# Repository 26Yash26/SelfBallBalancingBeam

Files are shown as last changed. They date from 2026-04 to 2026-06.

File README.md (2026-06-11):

# 🏓 Ping Pong Ball Balancer

> A PID-controlled system that autonomously balances a ping pong ball at the centre of a 420 mm bar using an ESP32-S3, dual VL53L0X time-of-flight sensors, and an MG995 servo motor.

```
[LEFT TOF]  <── dL ──── ● ──── dR ──>  [RIGHT TOF]
                    ball position = L − dR  (primary)

Servo tilts bar ──> ball rolls toward centre (210 mm)
```

---

## Table of Contents

1. [Project Overview](#1-project-overview)
2. [Hardware](#2-hardware)
3. [Hardware Pivot: Stepper → Servo](#3-hardware-pivot-stepper--servo)
4. [Wiring](#4-wiring)
5. [Mechanical Design (CAD)](#5-mechanical-design-cad)
6. [Sensor Reliability & Fusion](#6-sensor-reliability--fusion)
7. [PID Controller](#7-pid-controller)
8. [Hyperparameters](#8-hyperparameters)
9. [PID Tuning Procedure](#9-pid-tuning-procedure)
10. [Arduino IDE Setup](#10-arduino-ide-setup)
11. [Serial Monitor Output](#11-serial-monitor-output)
12. [Troubleshooting](#12-troubleshooting)

---

## 1. Project Overview

This project implements a closed-loop PID control system that balances a ping pong ball at the midpoint of a 420 mm aluminium bar. Two VL53L0X time-of-flight sensors measure the ball's position from each end; an ESP32-S3 microcontroller runs the control loop at 30 ms intervals; and an MG995 metal-gear servo physically tilts the bar to drive the ball back to the 210 mm setpoint.

The design went through one major hardware pivot — an initial attempt using a stepper motor was abandoned in favour of the MG995 servo. That journey is documented in [Section 3](#3-hardware-pivot-stepper--servo).

---

## 2. Hardware

| Component | Model / Spec | Notes |
|---|---|---|
| Microcontroller | ESP32-S3 N8R8 | Dual-core, 8 MB flash, 8 MB PSRAM |
| ToF Sensors ×2 | Adafruit VL53L0X | I2C, up to 2 m range; default addr `0x29` |
| Servo Motor | MG995 (metal gear) | 4.8–7.2 V, stall torque 13 kg·cm |
| Bar | 420 mm aluminium channel | Sensing distance between sensors |
| Power Supply | 5 V / 3 A dedicated | For servo only — never use ESP32 rail |

---

## 3. Hardware Pivot: Stepper → Servo

### 3.1 Initial Design — Stepper Motor Approach

The first iteration used a stepper motor for bar actuation, on the premise that steppers offer precise, repeatable positioning without a motor-side feedback sensor. Components used:

| Part | Model |
|---|---|
| Motor | NEMA 17 bipolar stepper — 17HS4401, 1.7 A/phase, 1.8°/step |
| Driver | A4988 stepper driver module (Pololu-style pinout) |
| Encoder | 600 PPR incremental rotary encoder (A/B quadrature) mounted on bar pivot shaft |

The encoder was added to provide absolute angle feedback, since the stepper could lose steps under rapid reversals.

### 3.2 Why It Didn't Work

Several fundamental problems emerged during testing:

- **Resonance and mid-speed torque drop** — The NEMA 17 exhibits a well-known torque null around 200–400 steps/sec, which coincided exactly with the bar oscillation frequency the PID loop was trying to command. The motor would stall or miss steps mid-correction.

- **Latency** — Step-pulse generation within a tight 30 ms PID loop created timing jitter. Achieving smooth motion required interrupt-driven step/dir code that conflicted with the I2C polling of both VL53L0X sensors.

- **Holding current noise** — At standstill, the stepper's holding current injected electrical noise into the 3.3 V rail, causing intermittent I2C bus errors on both sensors.

- **Encoder complexity** — Adding a quadrature encoder for actual angle tracking introduced interrupt-driven counter code and debouncing without resolving the core torque and latency problems.

- **Physical bulk** — The NEMA 17 + A4988 + encoder assembly was mechanically oversized for a lightweight ping pong bar, introducing unwanted rotational inertia at the pivot.

### 3.3 The Pivot — MG995 RC Servo

The system was redesigned around an MG995 metal-gear RC servo, which solved every listed problem:

- **Direct angle command** — A PWM pulse (500–2400 µs) maps directly to a shaft angle. No step counting, no lost-step risk, no encoder required.
- **Software speed limiting** — The `SERVO_SPEED` hyperparameter (max degrees per loop cycle) replaces mechanical damping with smooth, controllable motion.
- **Electrical isolation** — The servo runs from a dedicated 5 V/3 A rail; its signal line on GPIO 3 keeps the I2C bus clean.
- **Compact and lightweight** — At 55 g, the MG995 mounts directly under the bar pivot with a standard servo horn.

> **Trade-off:** The MG995 has a rated positioning accuracy of ~±1° and a dead-band of ~5 µs, which sets a practical lower bound on `DEADBAND_MM` (~25 mm). This is acceptable for the project goals.

---

## 4. Wiring

### 4.1 ToF Sensors — Dual I2C Buses

Both VL53L0X sensors share the default I2C address `0x29` and cannot share a bus without address remapping. Instead, two hardware I2C peripherals on the ESP32-S3 are used — one per sensor — eliminating any need to toggle XSHUT lines. **Leave XSHUT unconnected on both sensors.**

| ESP32-S3 Pin | Left VL53L0X | Right VL53L0X |
|---|---|---|
| GPIO 8 (SDA0) | SDA | — |
| GPIO 9 (SCL0) | SCL | — |
| GPIO 6 (SDA1) | — | SDA |
| GPIO 7 (SCL1) | — | SCL |
| 3.3V | VIN | VIN |
| GND | GND | GND |

### 4.2 MG995 Servo

| ESP32-S3 Pin | MG995 Wire | Notes |
|---|---|---|
| GPIO 3 | Signal (orange/yellow) | PWM via ESP32Servo library |
| GND (shared) | GND (black) | Must share with ESP32 GND |
| External 5V / 3A | VCC (red) | **Never** use ESP32 3.3V rail |

> ⚠️ **Warning:** The MG995 draws up to 2.5 A under stall load. Powering it from the ESP32's 3.3 V rail will brown-out the board. Always use a dedicated 5 V/3 A supply with its GND tied to the ESP32 GND.

---

## 5. Mechanical Design (CAD)

The bar pivots at its midpoint on a 3D-printed mount. The MG995 servo horn connects to a linkage arm that converts rotational motion into bar tilt. VL53L0X sensor brackets at each end hold the modules pointing inward along the bar axis.

<!-- CAD IMAGE 1: Replace the path below with your actual image -->
**Figure 1 — Isometric View **
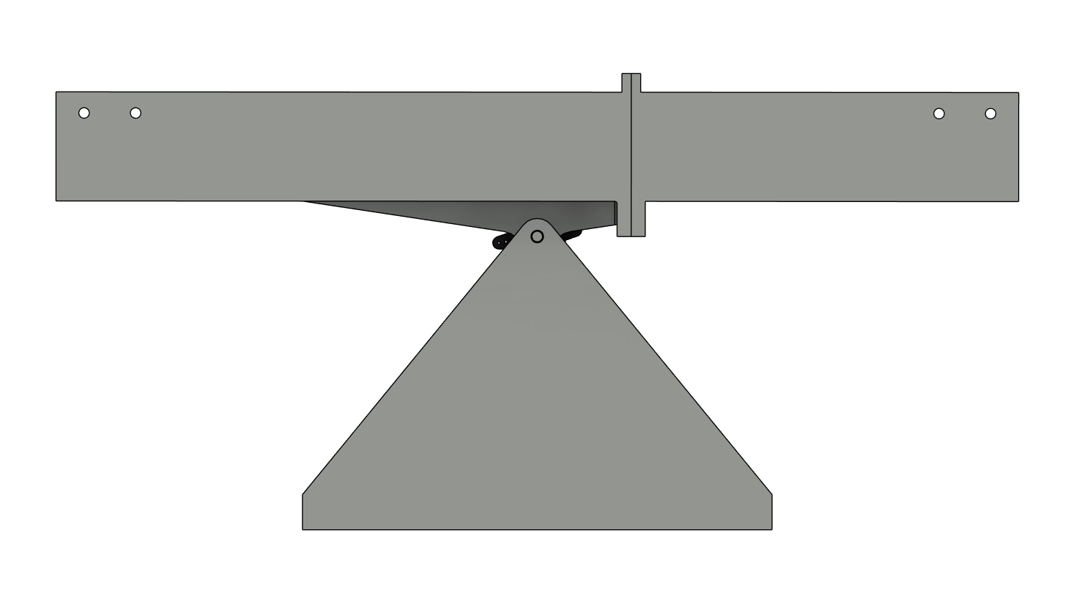
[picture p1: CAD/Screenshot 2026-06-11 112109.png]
CAD Isometric View


**Figure 2 — Exploded View (Servo Mount & Pivot Detail)**
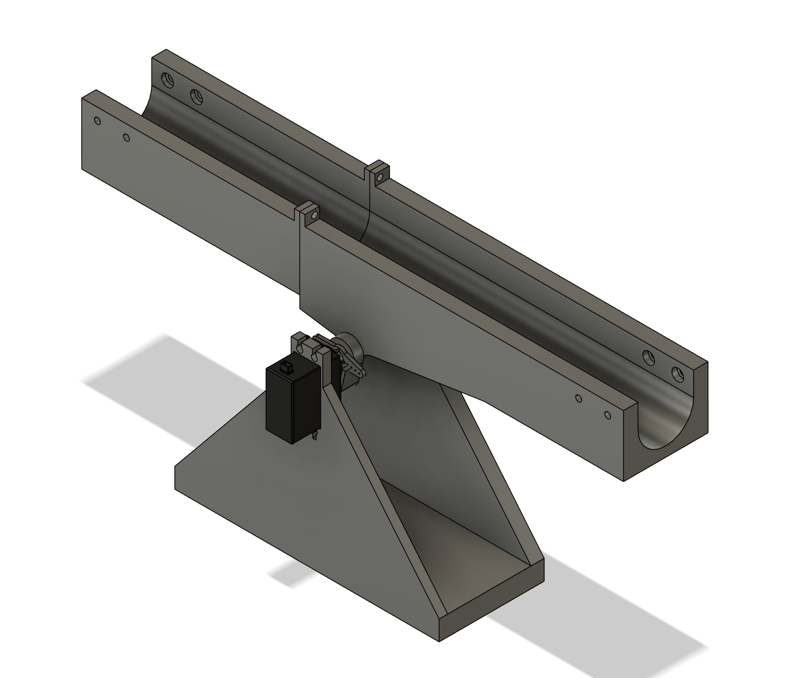
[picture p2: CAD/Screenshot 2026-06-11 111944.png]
CAD Exploded View


---

## 6. Sensor Reliability & Fusion

### 6.1 Trusted Ranges

The two sensors have different reliable operating ranges due to reflectivity and angle-of-incidence differences at extreme bar positions:

| Sensor | SDA / SCL | Trusted Range | Role |
|---|---|---|---|
| Left | GPIO 8 / 9 | 0 – 150 mm | Fallback (ball near left end) |
| Right | GPIO 6 / 7 | 0 – 300 mm | Primary |

### 6.2 Fusion Logic

| Condition | Position Used |
|---|---|
| Both sensors valid | Average of both estimates |
| Right only valid | `L − dR` |
| Left only valid | `dL` |
| Neither valid | No ball detected |

> **Blind spot:** There is a region approximately 120–150 mm from the left end where neither sensor is trusted. If the ball is consistently lost there, increase the left sensor threshold from `150` mm to `180` mm inside `fusePosition()` and verify readings remain stable.

---

## 7. PID Controller

### 7.1 What is a PID Controller?

A PID (Proportional-Integral-Derivative) controller is a feedback algorithm that computes a corrective output from three terms, each responding to a different characteristic of the error signal. Here the *error* is the deviation of the ball's measured position from the 210 mm setpoint.

| Term | Role | Effect if too high |
|---|---|---|
| **P** — Proportional | Correction ∝ current error. Large error → aggressive tilt; small error → gentle tilt. | Sustained oscillation around setpoint |
| **I** — Integral | Accumulates error over time, eliminating steady-state offset. | Slow, undamped oscillation that never settles |
| **D** — Derivative | Acts on the *rate of change* of error, braking fast approaches to prevent overshoot. | Noisy, jittery servo motion |

### 7.2 Error Function

```
e(t) = setpoint − position(t)
     = 210 mm − fused_ball_position(t)
```

A positive error (ball left of centre) should tilt the bar so the left side drops, rolling the ball right. A negative error does the opposite. The sign convention is verified during tuning Step 2.

### 7.3 Discrete PID Implementation

The controller runs on a fixed **30 ms** loop period. The continuous equations are discretised as:

```
P_term  = Kp × e[n]

I_term  = I_term + Ki × e[n]          // accumulate each cycle
          (reset if |e[n]| < DEADBAND_MM)  // anti-windup

D_term  = Kd × (e[n] − e[n-1])        // backward difference

PID_out = P_term + I_term + D_term

servo_angle = NEUTRAL_DEG − (int)PID_out  // swap sign if direction is inverted
servo_angle = clamp(servo_angle, SERVO_MIN_DEG, SERVO_MAX_DEG)
servo_angle = rate_limit(servo_angle, SERVO_SPEED)
```

The integral accumulator resets to zero whenever the error falls within `DEADBAND_MM`. This prevents **integrator windup** during the final approach to centre, where mechanical friction and sensor noise would otherwise cause the bar to oscillate with a growing integral component.

---

## 8. Hyperparameters

All tunable values are at the top of the sketch under the `// HYPERPARAMETERS` block.

| Parameter | Default | Description |
|---|---|---|
| `NEUTRAL_DEG` | `97` | Servo angle when bar is physically horizontal. **Set this first** before any gain tuning. |
| `SERVO_MIN_DEG` | `75` | Hard lower clamp on servo angle. |
| `SERVO_MAX_DEG` | `120` | Hard upper clamp on servo angle. |
| `SERVO_SPEED` | `3` | Max degrees the servo moves per 30 ms cycle. Higher = faster, lower = smoother. |
| `Kp` | `0.06` | Proportional gain. |
| `Ki` | `0.0004` | Integral gain. Keep very small (`0.0001`–`0.001`). |
| `Kd` | `0.45` | Derivative gain. Primary damping term. Start at `5 × Kp`. |
| `DEADBAND_MM` | `25` | Error within this window → servo holds neutral, integrator resets. |
| `NO_BALL_SLACK` | `50` | Tolerance for no-ball detection (mm). Raise if ball is ignored mid-bar. |
| `MIN_DIST_MM` | `20` | Readings below this are treated as noise / wall reflections. |

---

## 9. PID Tuning Procedure

Tune gains in strict order. Jumping ahead gives misleading results.

**Step 1 — Set `NEUTRAL_DEG`**
Zero all gains. Adjust `NEUTRAL_DEG` until the bar sits physically horizontal (use a spirit level). This is your mechanical baseline.

**Step 2 — Check correction direction**
Place the ball near one end. The bar should tilt to push the ball toward 210 mm. If it tilts the wrong way, swap the sign in the servo command line:
```cpp
// Change this:
NEUTRAL_DEG - (int)pidOut
// To this:
NEUTRAL_DEG + (int)pidOut
```

**Step 3 — Tune `Kp`** (Ki = 0, Kd = 0)
Increase `Kp` until the ball oscillates steadily around 210 mm. Back off ~30% from that value.

**Step 4 — Tune `Kd`**
Increase `Kd` to damp overshoot. Good starting point: `Kd = 5 × Kp`. Keep raising until oscillations settle without sluggishness.

**Step 5 — Tune `Ki` last**
Only add `Ki` if the ball consistently settles slightly off-centre. Start at `0.0001` and increase slowly. Too much causes a slow oscillation that never damps out.

---

## 10. Arduino IDE Setup

### Board Setup

1. **File → Preferences** → add to *Additional Boards Manager URLs*:
   ```
   https://raw.githubusercontent.com/espressif/arduino-esp32/gh-pages/package_esp32_index.json
   ```
2. **Tools → Board → Boards Manager** → search `esp32` → install **ESP32 by Espressif Systems**
3. **Tools → Board** → select **ESP32S3 Dev Module**
4. **Tools → Port** → select your COM port

### Required Libraries

Install all three via Arduino IDE Library Manager:

| Library | Search Term |
|---|---|
| ESP32Servo | `ESP32Servo` |
| Adafruit VL53L0X | `Adafruit VL53L0X` |
| Wire | Built-in (no install needed) |

---

## 11. Serial Monitor Output

Set baud rate to **115200**. Each line prints:

```
L:183mm   R:112mm   pos:308.0mm   err:-98.0   PID:-4.41   target:101   servo:100
```

| Column | Meaning |
|---|---|
| `L` | Raw left sensor reading (mm) |
| `R` | Raw right sensor reading (mm) |
| `pos` | Fused ball position from left end (mm) |
| `err` | Position error = `210 − pos` |
| `PID` | PID controller output (degrees offset) |
| `target` | Servo angle requested this cycle (post-PID) |
| `servo` | Actual servo angle after speed-limiting clamp |

---

## 12. Troubleshooting

**Servo not moving**
- Verify GND is shared between ESP32 and the external 5V supply.
- Flash a servo debug sketch and confirm pulses appear on GPIO 3 in Serial Monitor.

**Sensor `FAILED` on boot**
- Check VIN is connected to 3.3V, not 5V.
- Verify SDA/SCL pin assignments match the `#define` values in the sketch.
- Try reducing I2C clock: change `400000` → `100000` in `I2C_left.begin()`.

**Ball rolls to one end and stays**
- Correction direction is inverted — swap `+` and `−` in the servo command line.
- `Kp` is too low — raise it until the bar reacts visibly.

**Ball oscillates and won't settle**
- Raise `Kd` to damp overshoot.
- Increase `DEADBAND_MM` to widen the neutral zone.
- Reduce `SERVO_SPEED` for smoother motion.

**Ball gets lost mid-bar**
- Left sensor blind spot (120–150 mm region) — increase left sensor threshold from `150` to `180` mm in `fusePosition()`.
- Check `NO_BALL_SLACK` is large enough; raise from `50` mm if needed.

**Slow oscillation that never damps**
- `Ki` is too large — reduce or set to zero and retune from Step 5.

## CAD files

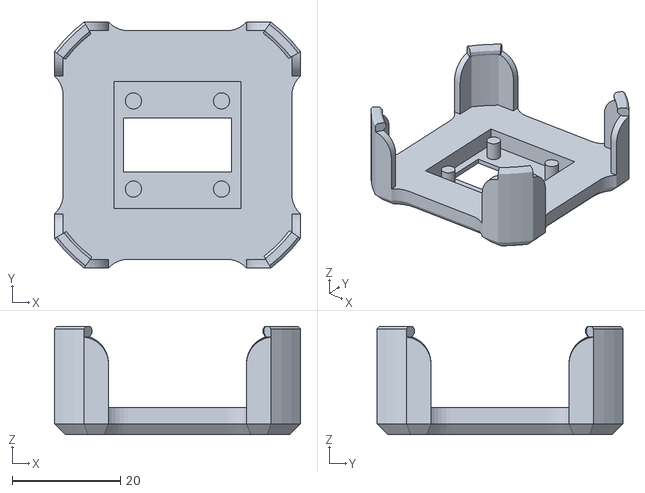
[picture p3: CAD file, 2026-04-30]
AS5600_holder.STL
45.4 x 45.4 x 20.0

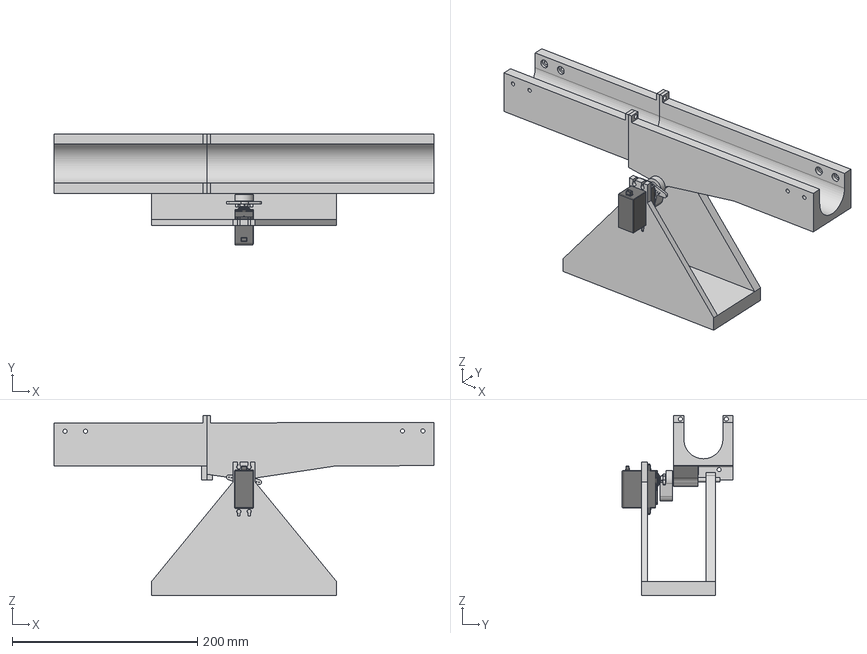
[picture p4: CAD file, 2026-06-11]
CAD/Ball_balencing.step
410.0 x 119.9 x 194.5 mm

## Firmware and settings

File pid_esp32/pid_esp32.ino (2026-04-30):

#include <Wire.h>
#include "Adafruit_VL53L0X.h"
#include <ESP32Servo.h>

// ── Pins ─────────────────────────────────────────────────────
#define SDA0      8
#define SCL0      9
#define SDA1      6
#define SCL1      7
#define SERVO_PIN 3

// ═════════════════════════════════════════════════════════════
//  HYPERPARAMETERS — tune these
// ═════════════════════════════════════════════════════════════

const int   SERVO_MIN_DEG  = 75;    // maximum tilt one way
const int   SERVO_MAX_DEG  = 120;   // maximum tilt other way
const int   NEUTRAL_DEG    = 97;    // bar level position — adjust until bar is flat
const int   SERVO_SPEED    = 2;     // degrees per cycle — higher = faster response
const int   NO_BALL_SLACK  = 50;    // mm — increase if ball gets ignored
const int   MIN_DIST_MM    = 20;    // mm — ignore readings below this
const float DEADBAND_MM    = 25.0f; // mm — within this error, just level the bar

float Kp = 0.06f;
float Ki = 0.0004f;
float Kd = 0.45f;

// ═════════════════════════════════════════════════════════════

const float L_MM        = 420.0f;
const float SETPOINT_MM = L_MM / 2.0f;  // 210 mm

const unsigned long DT_MS = 30;

// ── PID state ────────────────────────────────────────────────
float integral          = 0.0f;
float prevError         = 0.0f;
bool  firstLoop         = true;
int   currentServoAngle = NEUTRAL_DEG;

// ── Objects ──────────────────────────────────────────────────
TwoWire I2C_left  = TwoWire(0);
TwoWire I2C_right = TwoWire(1);
Adafruit_VL53L0X tofLeft;
Adafruit_VL53L0X tofRight;
Servo myServo;

unsigned long lastTime = 0;

// ─────────────────────────────────────────────────────────────
//  Helpers
// ─────────────────────────────────────────────────────────────
float clampf(float v, float lo, float hi) {
  return (v < lo) ? lo : (v > hi) ? hi : v;
}
int clampInt(int v, int lo, int hi) {
  return (v < lo) ? lo : (v > hi) ? hi : v;
}

void servoMoveTo(int target) {
  target = clampInt(target, SERVO_MIN_DEG, SERVO_MAX_DEG);
  if (target == currentServoAngle) return;

  int step = (target > currentServoAngle) ? SERVO_SPEED : -SERVO_SPEED;
  currentServoAngle += step;

  if (step > 0 && currentServoAngle > target) currentServoAngle = target;
  if (step < 0 && currentServoAngle < target) currentServoAngle = target;

  currentServoAngle = clampInt(currentServoAngle, SERVO_MIN_DEG, SERVO_MAX_DEG);
  myServo.write(currentServoAngle);
}

float readMM(Adafruit_VL53L0X &sensor) {
  VL53L0X_RangingMeasurementData_t m;
  sensor.rangingTest(&m, false);
  if (m.RangeStatus == 4)                return -1.0f;  // out of range
  if (m.RangeMilliMeter < MIN_DIST_MM)   return -1.0f;  // too close, noise
  return (float)m.RangeMilliMeter;
}

// Right sensor is primary (more accurate).
// Left sensor is fallback only — used when ball is near left end.
float fusePosition(float dL, float dR) {
  bool leftOk  = (dL > 0 && dL < 150.0f);   // left only trusted below 150mm
  bool rightOk = (dR > 0 && dR < 200.0f);   // right trusted up to 300mm

  if (rightOk && leftOk) {
    // Both reliable — average them
    return (dL + (L_MM - dR)) / 2.0f;
  }
  if (rightOk) return L_MM - dR;   // right only (primary)
  if (leftOk)  return dL;          // left only (ball very close to left end)
  return -1.0f;                     // no ball
}

// ─────────────────────────────────────────────────────────────
//  Setup
// ─────────────────────────────────────────────────────────────
void setup() {
  Serial.begin(115200);
  delay(500);
  Serial.println("\n=== Ball Balancer Boot ===");

  // ── Servo ────────────────────────────────────────────────
  ESP32PWM::allocateTimer(0);
  myServo.setPeriodHertz(50);
  myServo.attach(SERVO_PIN, 500, 2400);
  myServo.write(NEUTRAL_DEG);
  currentServoAngle = NEUTRAL_DEG;
  delay(600);
  Serial.print("Servo: OK  (limits: ");
  Serial.print(SERVO_MIN_DEG);
  Serial.print("° – ");
  Serial.print(SERVO_MAX_DEG);
  Serial.println("°)");

  // ── Left sensor ──────────────────────────────────────────
  I2C_left.begin(SDA0, SCL0, 400000);
  Serial.print("Left  sensor (fallback)... ");
  if (!tofLeft.begin(0x29, false, &I2C_left)) {
    Serial.println("FAILED. Check SDA->GPIO8, SCL->GPIO9.");
    while (1);
  }
  Serial.println("OK");

  // ── Right sensor ─────────────────────────────────────────
  I2C_right.begin(SDA1, SCL1, 400000);
  Serial.print("Right sensor (primary)... ");
  if (!tofRight.begin(0x29, false, &I2C_right)) {
    Serial.println("FAILED. Check SDA->GPIO6, SCL->GPIO7.");
    while (1);
  }
  Serial.println("OK");

  Serial.println("--------------------------------------------------------");
  Serial.println("Place ball on bar.");
  Serial.println("L(mm)\tR(mm)\tpos\terr\tPID\ttarget\tservo");
  Serial.println("--------------------------------------------------------");

  lastTime = millis();
}

// ─────────────────────────────────────────────────────────────
//  Main loop
// ─────────────────────────────────────────────────────────────
void loop() {
  unsigned long now = millis();
  if (now - lastTime < DT_MS) return;
  float dt = (now - lastTime) / 1000.0f;
  lastTime = now;

  float dL  = readMM(tofLeft);
  float dR  = readMM(tofRight);
  float pos = fusePosition(dL, dR);

  // ── No ball → return to neutral, reset PID ───────────────
  if (pos < 0) {
    integral  = 0;
    prevError = 0;
    firstLoop = true;
    servoMoveTo(NEUTRAL_DEG);
    Serial.print("L:"); Serial.print(dL, 0);
    Serial.print("mm\tR:"); Serial.print(dR, 0);
    Serial.println("mm\t-- no ball --");
    return;
  }

  // ── PID ──────────────────────────────────────────────────
  float error      = SETPOINT_MM - pos;
  float derivative = firstLoop ? 0.0f : (error - prevError) / dt;
  firstLoop        = false;

  integral += error * dt;
  integral  = clampf(integral, -500.0f, 500.0f);

  float pidOut = Kp * error
               + Ki * integral
               + Kd * derivative;

  // ── Deadband + servo command ──────────────────────────────
  int targetAngle;
  if (fabs(error) < DEADBAND_MM) {
    targetAngle = NEUTRAL_DEG;   // ball close enough → level bar
    integral    = 0;             // prevent integrator windup at rest
  } else {
    targetAngle = clampInt(NEUTRAL_DEG - (int)pidOut, SERVO_MIN_DEG, SERVO_MAX_DEG);
  }

  servoMoveTo(targetAngle);
  prevError = error;

  // ── Telemetry ─────────────────────────────────────────────
  Serial.print("L:"); Serial.print(dL, 0);
  Serial.print("mm\tR:"); Serial.print(dR, 0);
  Serial.print("mm\tpos:"); Serial.print(pos, 1);
  Serial.print("mm\terr:"); Serial.print(error, 1);
  Serial.print("\tPID:"); Serial.print(pidOut, 2);
  Serial.print("\ttarget:"); Serial.print(targetAngle);
  Serial.print("\tservo:"); Serial.println(currentServoAngle);
}

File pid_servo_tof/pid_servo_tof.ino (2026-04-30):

/*
 * ================================================================
 *  PING-PONG BALL BALANCER  —  Single PID with MG995 Servo
 *  Arduino Uno R3
 * ================================================================
 *
 *  PID:  error = (L/2) − tof_distance  =  210 − dist_mm
 *        setpoint = 0  (ball at bar centre)
 *        output   = angle offset added to servo neutral (90°)
 *
 *  WIRING:
 *    D3          → Servo signal wire (orange/yellow)
 *    A4 (SDA)    → VL53L0X SDA
 *    A5 (SCL)    → VL53L0X SCL
 *    5V          → VL53L0X VIN
 *    GND         → VL53L0X GND + Servo GND (black)
 *    External 5V → Servo VCC (red)  ← NOT Arduino 5V
 *
 *  LIBRARIES:
 *    Servo           (built-in)
 *    Adafruit VL53L0X
 *    Wire            (built-in)
 * ================================================================
 */

#include <Wire.h>
#include <Servo.h>
#include "Adafruit_VL53L0X.h"

// ── Pin ──────────────────────────────────────────────────────
#define SERVO_PIN 3

// ── Physical constants ───────────────────────────────────────
const float L_MM          = 420.0f;       // bar sensing length (mm)
const float SETPOINT_MM   = L_MM / 2.0f;  // 210 mm — ball target
const int   NEUTRAL_DEG   = 90;           // servo angle when bar is level
                                           // ↑ adjust if bar isn't perfectly
                                           //   horizontal at 90°
const int   MAX_TILT_DEG  = 20;           // max offset from neutral (±20°)
const unsigned long DT_MS = 30;           // loop period — ~33 Hz

// ── PID gains ────────────────────────────────────────────────
// Tune Kp first, then Kd, then Ki last (usually stays near 0).
float Kp = 0.06f;
float Ki = 0.0004f;
float Kd = 0.45f;

// ── PID state ────────────────────────────────────────────────
float integral    = 0.0f;
float prevError   = 0.0f;
bool  firstLoop   = true;

// ── Objects ──────────────────────────────────────────────────
Servo             myServo;
Adafruit_VL53L0X  tof;

// ── Timing ───────────────────────────────────────────────────
unsigned long lastTime = 0;

// ─────────────────────────────────────────────────────────────
//  Helpers
// ─────────────────────────────────────────────────────────────

int clampInt(int v, int lo, int hi) {
  return (v < lo) ? lo : (v > hi) ? hi : v;
}

float clampf(float v, float lo, float hi) {
  return (v < lo) ? lo : (v > hi) ? hi : v;
}

// Returns distance in mm, or -1 if ball is out of range
float tofDistMM() {
  VL53L0X_RangingMeasurementData_t m;
  tof.rangingTest(&m, false);
  return (m.RangeStatus != 4) ? (float)m.RangeMilliMeter : -1.0f;
}

// Write servo, always clamped to 0–180
void servoWrite(int deg) {
  myServo.write(clampInt(deg, 0, 180));
}

// ─────────────────────────────────────────────────────────────
//  Setup
// ─────────────────────────────────────────────────────────────
void setup() {
  Serial.begin(9600);

  // ── Servo ────────────────────────────────────────────────
  myServo.attach(SERVO_PIN);
  servoWrite(NEUTRAL_DEG);   // level bar before anything else
  delay(600);                // let servo reach neutral
  Serial.println("Servo ready.");

  // ── I2C + VL53L0X ───────────────────────────────────────
  Wire.begin();
  Wire.setClock(400000);
  Serial.print("Initialising VL53L0X... ");
  if (!tof.begin()) {
    Serial.println("FAILED. Check SDA->A4, SCL->A5, VIN->5V.");
    while (1);
  }
  Serial.println("OK");

  Serial.println("==============================================");
  Serial.println("  Balancer running. Place ball on bar.       ");
  Serial.println("  dist(mm)  error  PID_out  servoAngle       ");
  Serial.println("==============================================");

  lastTime = millis();
}

// ─────────────────────────────────────────────────────────────
//  Main loop  (~33 Hz)
// ─────────────────────────────────────────────────────────────
void loop() {
  unsigned long now = millis();
  if (now - lastTime < DT_MS) return;
  float dt = (now - lastTime) / 1000.0f;
  lastTime = now;

  float dist = tofDistMM();

  // ── No ball → hold level, reset integrator ───────────────
  if (dist < 0) {
    integral  = 0;
    prevError = 0;
    firstLoop = true;
    servoWrite(NEUTRAL_DEG);
    Serial.println("-- no ball --");
    return;
  }

  // ── PID ──────────────────────────────────────────────────
  float error = SETPOINT_MM - dist;   // positive: ball too close → tilt away
                                       // negative: ball too far   → tilt toward

  // Skip derivative on first reading (prevError is meaningless)
  float derivative = firstLoop ? 0.0f : (error - prevError) / dt;
  firstLoop = false;

  integral += error * dt;
  integral  = clampf(integral, -500.0f, 500.0f);  // anti-windup

  float pidOut = Kp * error
               + Ki * integral
               + Kd * derivative;

  // Clamp PID output to safe tilt range
  pidOut = clampf(pidOut, -(float)MAX_TILT_DEG, (float)MAX_TILT_DEG);

  // Map to servo angle: positive error → tilt bar so ball rolls toward centre
  // If ball rolls the WRONG way, change (NEUTRAL_DEG + pidOut) to (NEUTRAL_DEG - pidOut)
  int servoAngle = NEUTRAL_DEG + (int)pidOut;

  servoWrite(servoAngle);
  prevError = error;

  // ── Telemetry ────────────────────────────────────────────
  Serial.print(dist, 0);       Serial.print('\t');
  Serial.print(error, 1);      Serial.print('\t');
  Serial.print(pidOut, 2);     Serial.print('\t');
  Serial.println(servoAngle);
}

/*
 * ================================================================
 *  TUNING GUIDE
 * ================================================================
 *
 *  1. CHECK DIRECTION FIRST
 *     Place ball near one end. The bar should tilt to push ball
 *     toward centre. If it tilts the wrong way, change:
 *       int servoAngle = NEUTRAL_DEG + (int)pidOut;
 *     to:
 *       int servoAngle = NEUTRAL_DEG - (int)pidOut;
 *
 *  2. SET NEUTRAL_DEG
 *     With Kp/Ki/Kd all at 0, the servo sits at NEUTRAL_DEG.
 *     Adjust until the bar is physically level.
 *
 *  3. TUNE Kp FIRST  (Ki=0, Kd=0)
 *     Raise Kp until ball oscillates back and forth around centre.
 *     Back it off ~30% from that point.
 *
 *  4. ADD Kd to kill overshoot and oscillation.
 *     Typical range: 5× to 10× Kp.
 *
 *  5. ADD Ki last, only if ball drifts to one side.
 *     Keep it tiny (0.0001 to 0.001). Too much = slow oscillation.
 *
 *  TYPICAL STARTING POINT (420 mm bar, MG995, VL53L0X):
 *    Kp = 0.06,  Ki = 0.0004,  Kd = 0.45
 *    NEUTRAL_DEG = 90,  MAX_TILT_DEG = 20
 * ================================================================
 */

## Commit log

2026-04-30 adding folders
    [AS5600_holder.STL]
2026-06-11 CAD files
    [Ball_balencing.step]
